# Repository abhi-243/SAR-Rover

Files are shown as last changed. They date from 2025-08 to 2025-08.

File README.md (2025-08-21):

# 🛠️ Search & Rescue Aid Robot

**A robust, low-cost, remote-controlled robot designed to aid first responders in post-disaster environments by scouting hazardous zones, identifying survivors, and streaming live footage—all while remaining compact and modular.**

---

## 📦 Contents  

- `CAD/` – Final 3D CAD models (Fusion 360)
- `STL/` – Exported 3D printable files
- `Drawings/` – Engineering drawings for fabrication
- `Code/` – ESP32-based Arduino code (motor control, IR LED, dual-camera switching, Bluetooth control via Dabble)
- `Media/` – Rendered images and beauty shots of the final design

---

## 🎯 Project Overview

Disasters like earthquakes and building collapses often trap survivors in unreachable spaces. This robot was designed to:

- **Navigate rubble** using dual-track movement and a low-profile body
- **Stream live video** via FPV cameras (day + IR night vision)
- **Be remotely controlled** using Bluetooth and the Dabble Gamepad interface
- **Be fabricated affordably** using common tools, 3D printed parts, and repurposed components (e.g. Ryobi tool batteries)

> 💡 Designed with scalability and accessibility in mind for use in developing regions or student labs.

---

## 🧠 Core Features

| Feature | Description |
|---|---|
| **Mobility** | Tank-style treads with adjustable belt tension system |
| **Dual Camera System** | Day + IR night vision with software-based switching |
| **Controller** | ESP32 microcontroller + Bluetooth + Dabble mobile interface |
| **Frame** | Acrylic chassis with 3D-printed and laser-cut elements |
| **Power** | Standard 18V Ryobi power tool battery integration |
| **Lighting** | Array of infrared and visible LEDs for enhanced visibility |

---

## 🧬 Technical Specifications

- **Microcontroller**: ESP32
- **Motor Driver**: BTS7960
- **Motors**: 12V DC gear motors (approx. 10,200 RPM)
- **Camera**: Foxeer FPV with IR switching circuit
- **Battery**: Ryobi 18V tool battery
- **Control Interface**: Dabble Gamepad via Bluetooth
- **Track System**: Dual chain + GT2 belt drive
- **Body Material**: 4.5mm Acrylic (lasercut and bent)
- **All other parts**: PETG (ABS is better, but PLA also works) 3D printed components

---

## 🧪 Code Overview

Main controller logic includes:
- Speed ramping on joystick input
- Differential drive for turns
- Camera switching via button
- IR lighting and LED toggle

```cpp
if (GamePad.isUpPressed()) {
  motors.forwardA(); motors.forwardB();
  speedness += speedAmount;
}
...
if (GamePad.isTrianglePressed()) {
  digitalWrite(cam, HIGH);  // Toggle camera
}
```

> 📂 See [`/Code/main.ino`](./Code/main.ino) for full source.

---

## 🖨️ Manufacturing Instructions

- Print STL files using PLA+ with 100% infill for structural components.
- Laser cut acrylic sheets using templates provided in `/Drawings/`.
- Bend chassis with acrylic bender based on Fusion 360 flat patterns.
- Assemble with M3–M5 bolts and collars per engineering drawings.

---

## 🧪 Testing Notes

- All individual systems (motors, cameras, Bluetooth) confirmed functional
- Movement subsystem had traction issues due to belt tensioning—future revisions planned

---

## 📸 Gallery

### Final Design

| Render1 | Render2 |
|:---:|:---:|
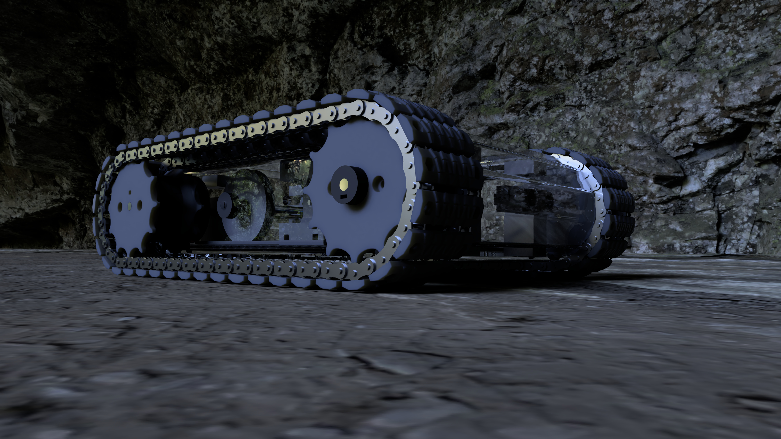
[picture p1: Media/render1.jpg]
Render3
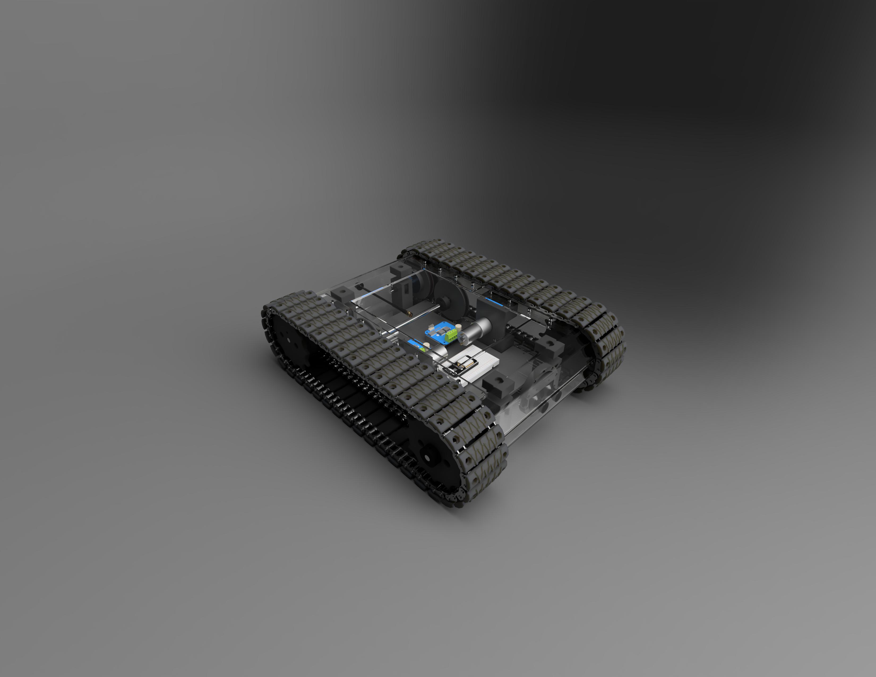
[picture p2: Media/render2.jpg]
Render4
|  |  |

----

### Animation

[Watch the demo](https://youtu.be/A4exE1CUXJw)

---

## 📚 Inspiration

Inspired by:
- [rctestflight snowcat robot](https://www.youtube.com/@rctestflight)
- Search-and-rescue robotics in earthquake zones
- Open-source robotics communities and Thingiverse designs

---

## 🤝 Acknowledgements

- **Mentors**: Mr. Jin Son (Design Theory), Mr. Rowan Simpson (Engineering)
- **Special thanks** to online creators and FPV drone community for documentation and hardware guidance

---

## 🧾 License

This project is released as **open hardware** and **open-source software**. Reuse, remix, and improve freely with attribution.

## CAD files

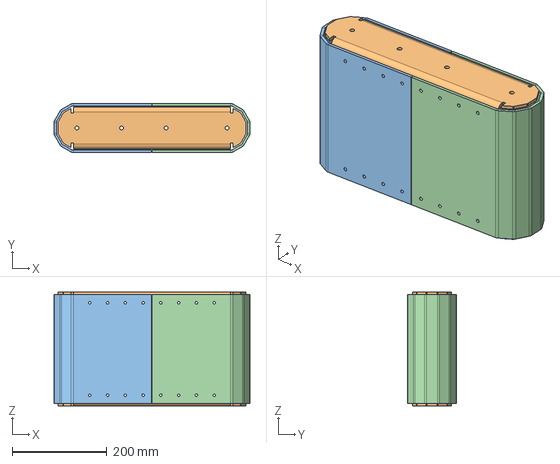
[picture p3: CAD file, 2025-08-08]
CAD/Body.step
413.5 x 103.8 x 240.0 mm

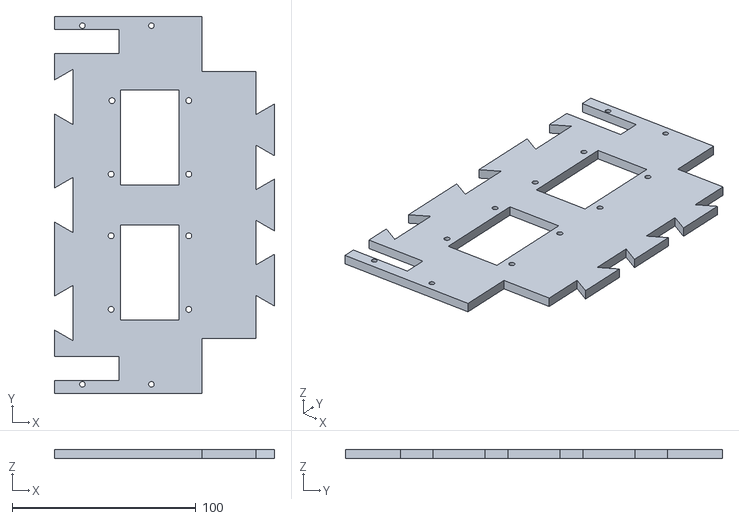
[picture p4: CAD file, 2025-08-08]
STLs/electronics mount-c.stl
119.7 x 205.0 x 5.00

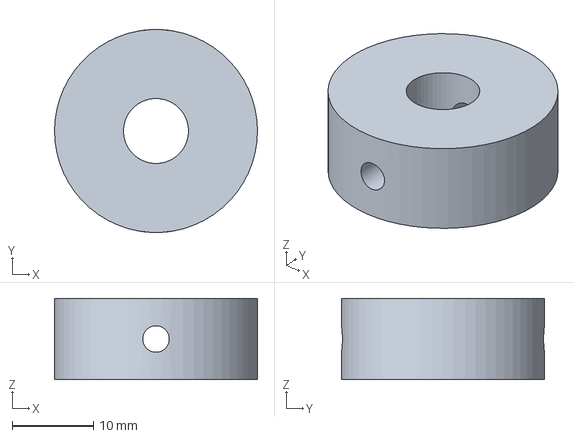
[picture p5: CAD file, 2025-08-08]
CAD/Shaft Collars.step
25.0 x 25.0 x 10.0 mm

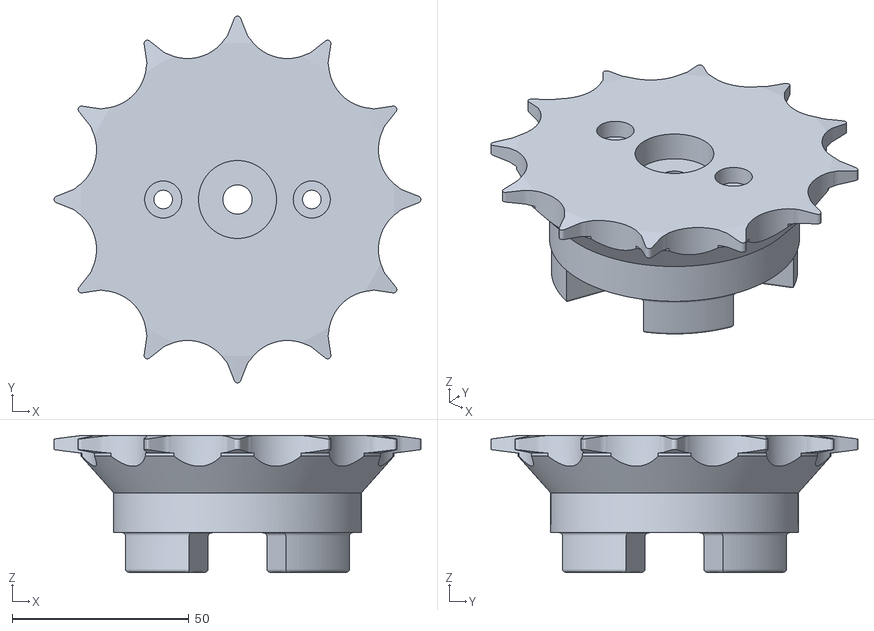
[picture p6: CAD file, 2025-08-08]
STLs/Sprocket v9 A.stl
103.8 x 103.8 x 38.8

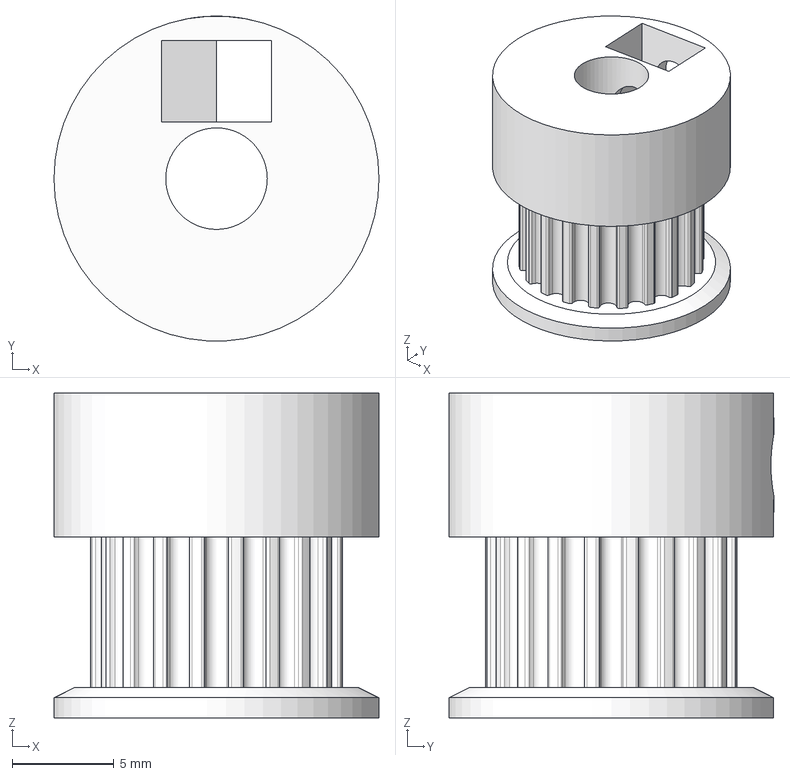
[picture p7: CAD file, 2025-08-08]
CAD/GT2 20T.step
16.0 x 16.0 x 16.0 mm

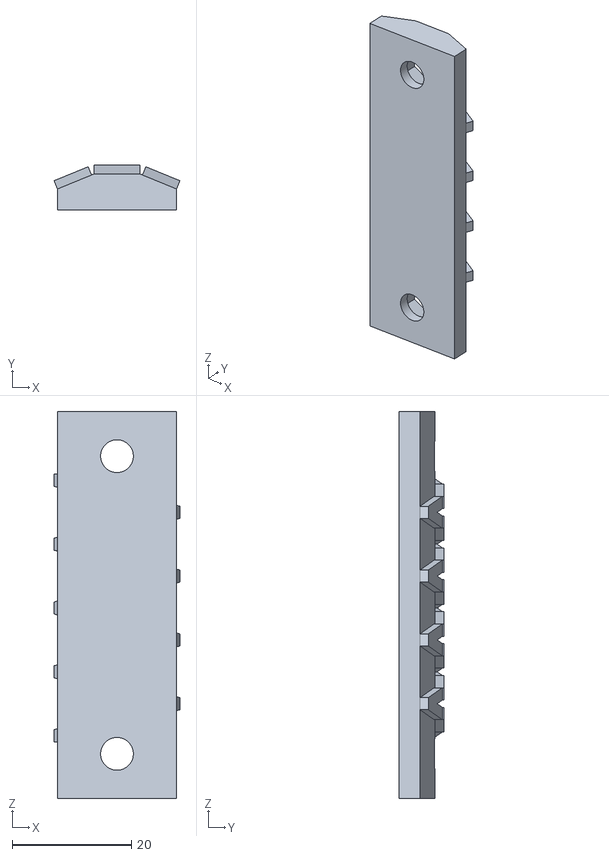
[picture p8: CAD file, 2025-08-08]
STLs/Tread Design 5.stl
21.1 x 7.50 x 65.0

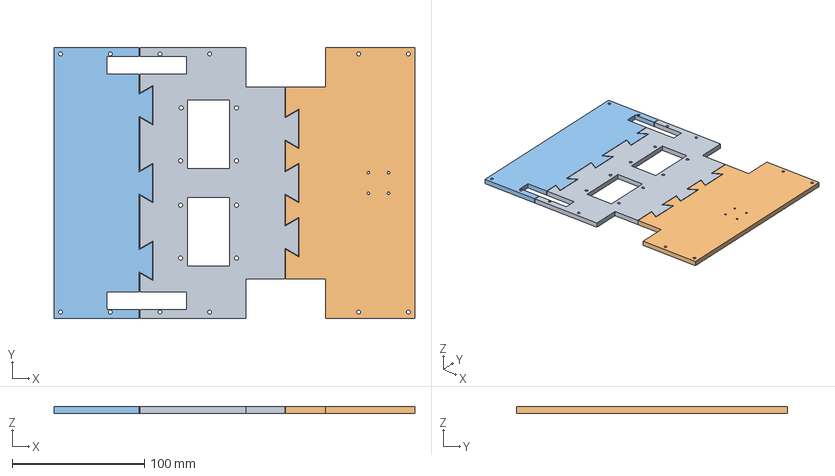
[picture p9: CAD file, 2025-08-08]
CAD/Electronics Mount.step
272.6 x 205.0 x 5.00 mm

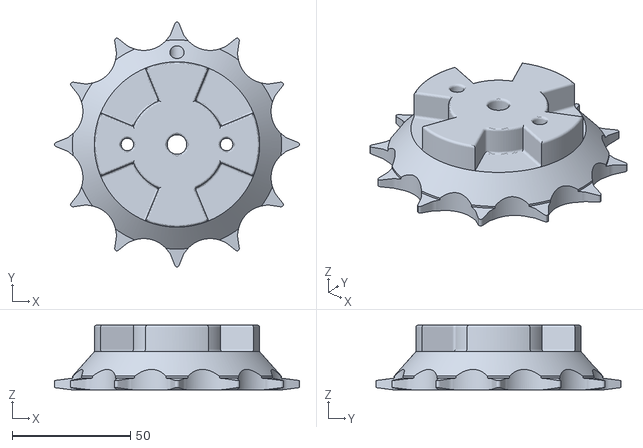
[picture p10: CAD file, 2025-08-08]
STLs/Drive Sprocket v9 B.stl
103.8 x 103.8 x 27.5

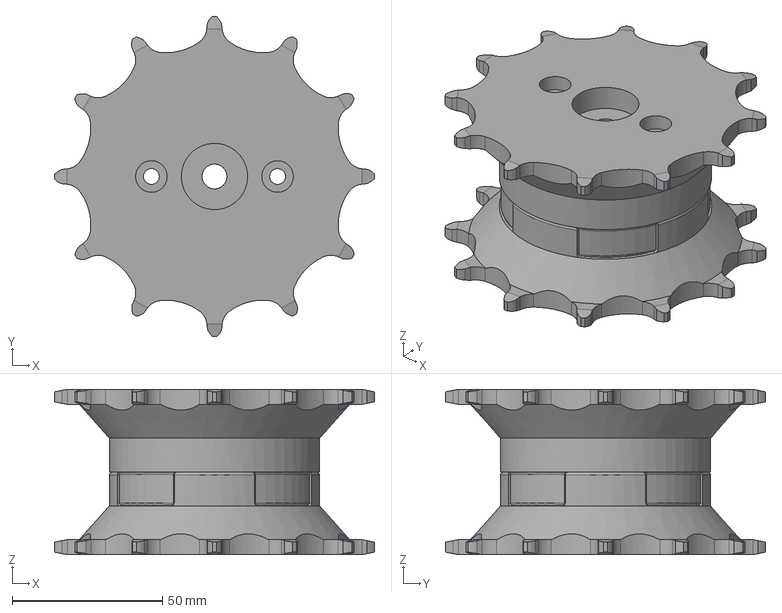
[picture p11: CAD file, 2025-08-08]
CAD/Sprocket.step
106.5 x 106.5 x 55.0 mm

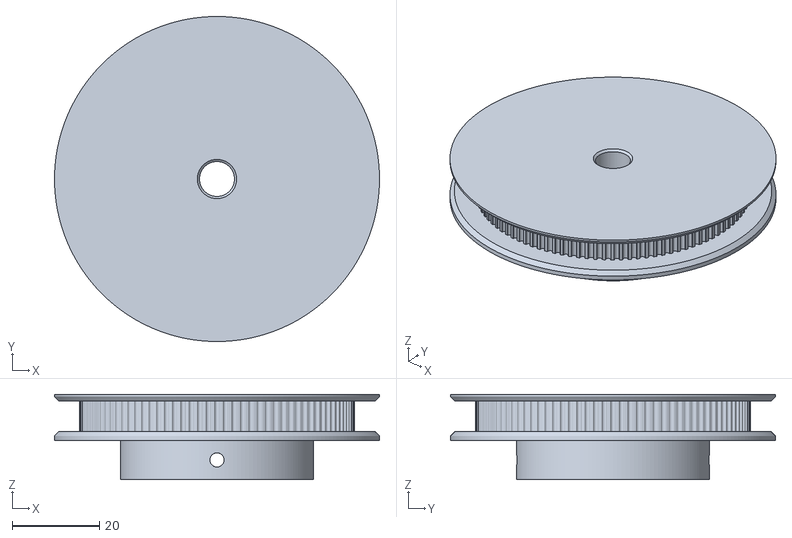
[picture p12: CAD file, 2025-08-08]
STLs/GT2 100T 8mm.stl
74.5 x 74.5 x 19.5

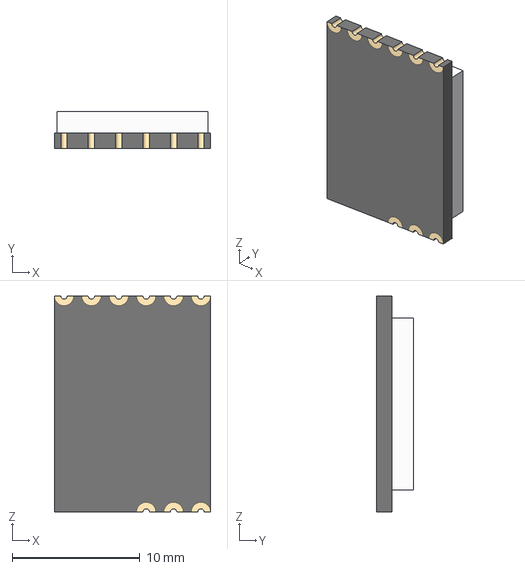
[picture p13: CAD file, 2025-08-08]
CAD/Rush Tank Tiny 5.8GHz VTX w Smart Audio.step
12.2 x 2.90 x 16.9 mm

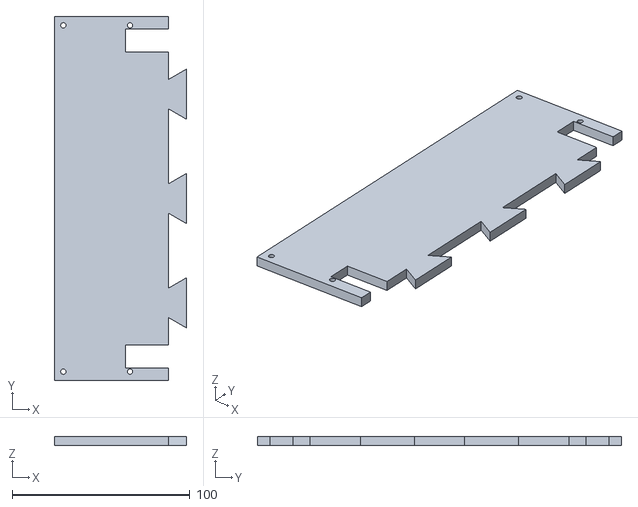
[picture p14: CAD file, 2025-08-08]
STLs/electronics mount-b.stl
74.3 x 205.0 x 5.00

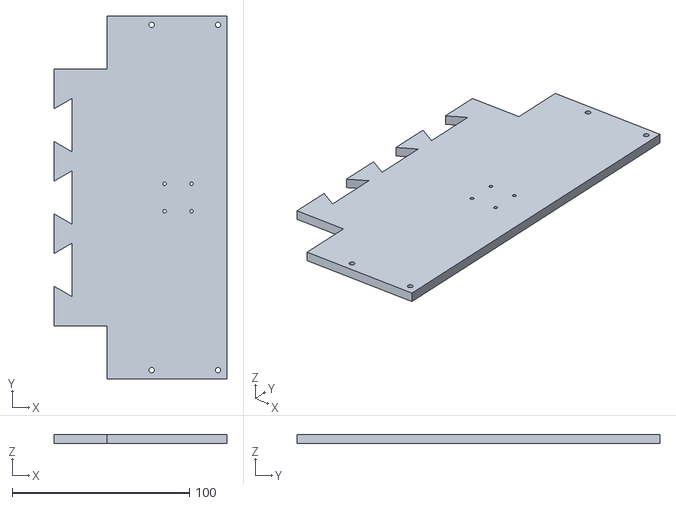
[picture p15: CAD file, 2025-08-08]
STLs/electronics mount-a.stl
97.6 x 205.0 x 5.00

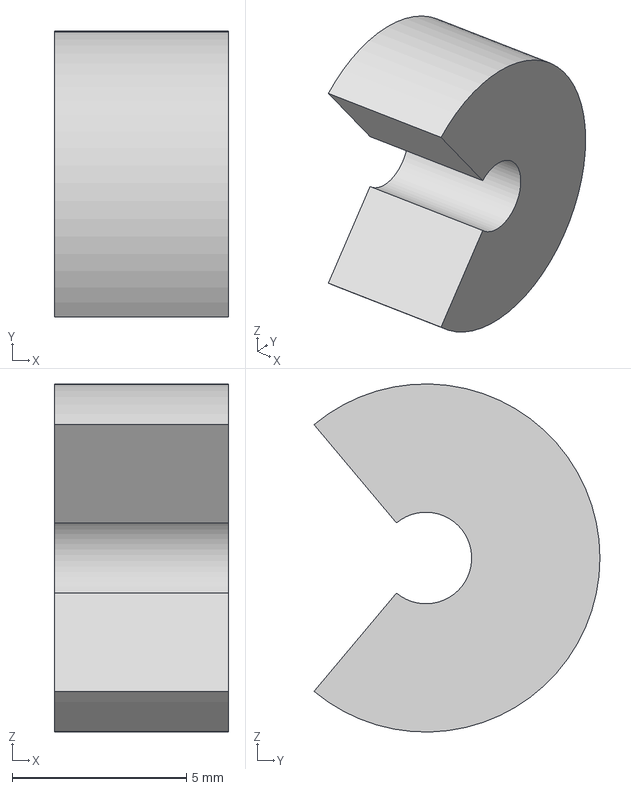
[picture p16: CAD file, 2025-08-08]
CAD/collar.step
5.00 x 8.21 x 10.00 mm

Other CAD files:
CAD/Drive Sprocket.step
STLs/light mount.stl
CAD/Shaft.step
STLs/Drive Sprocket v9 A.stl
CAD/36RPM 12VDC Reversible Gearhead Motor.step
CAD/BTS7960 H-Bridge Module.step
CAD/Camera.step
CAD/Combined 2.step
CAD/Lid Handles.step
CAD/Lumenier Double AXII 2 Long Range Antenna 5.8GHz Straight SMA RHCP.step
CAD/NodeMCU-32S-USBC-38pin-Narrow.step
CAD/Parametric GT2 100 pulley.step
CAD/Rush Tank Tiny Sled.step
CAD/Shaft Support.step
CAD/Treads.step
CAD/ViFly Cam Switcher.step
CAD/collar.dxf
CAD/motor mount.step
STLs/Chain_lock.stl
STLs/GT2 20T 5mm.stl
STLs/Shaft Collar 1.stl
STLs/Sprocket v9 B.stl
STLs/motor mount.stl
STLs/support 1.stl
STLs/support 2.stl
STLs/washer.stl

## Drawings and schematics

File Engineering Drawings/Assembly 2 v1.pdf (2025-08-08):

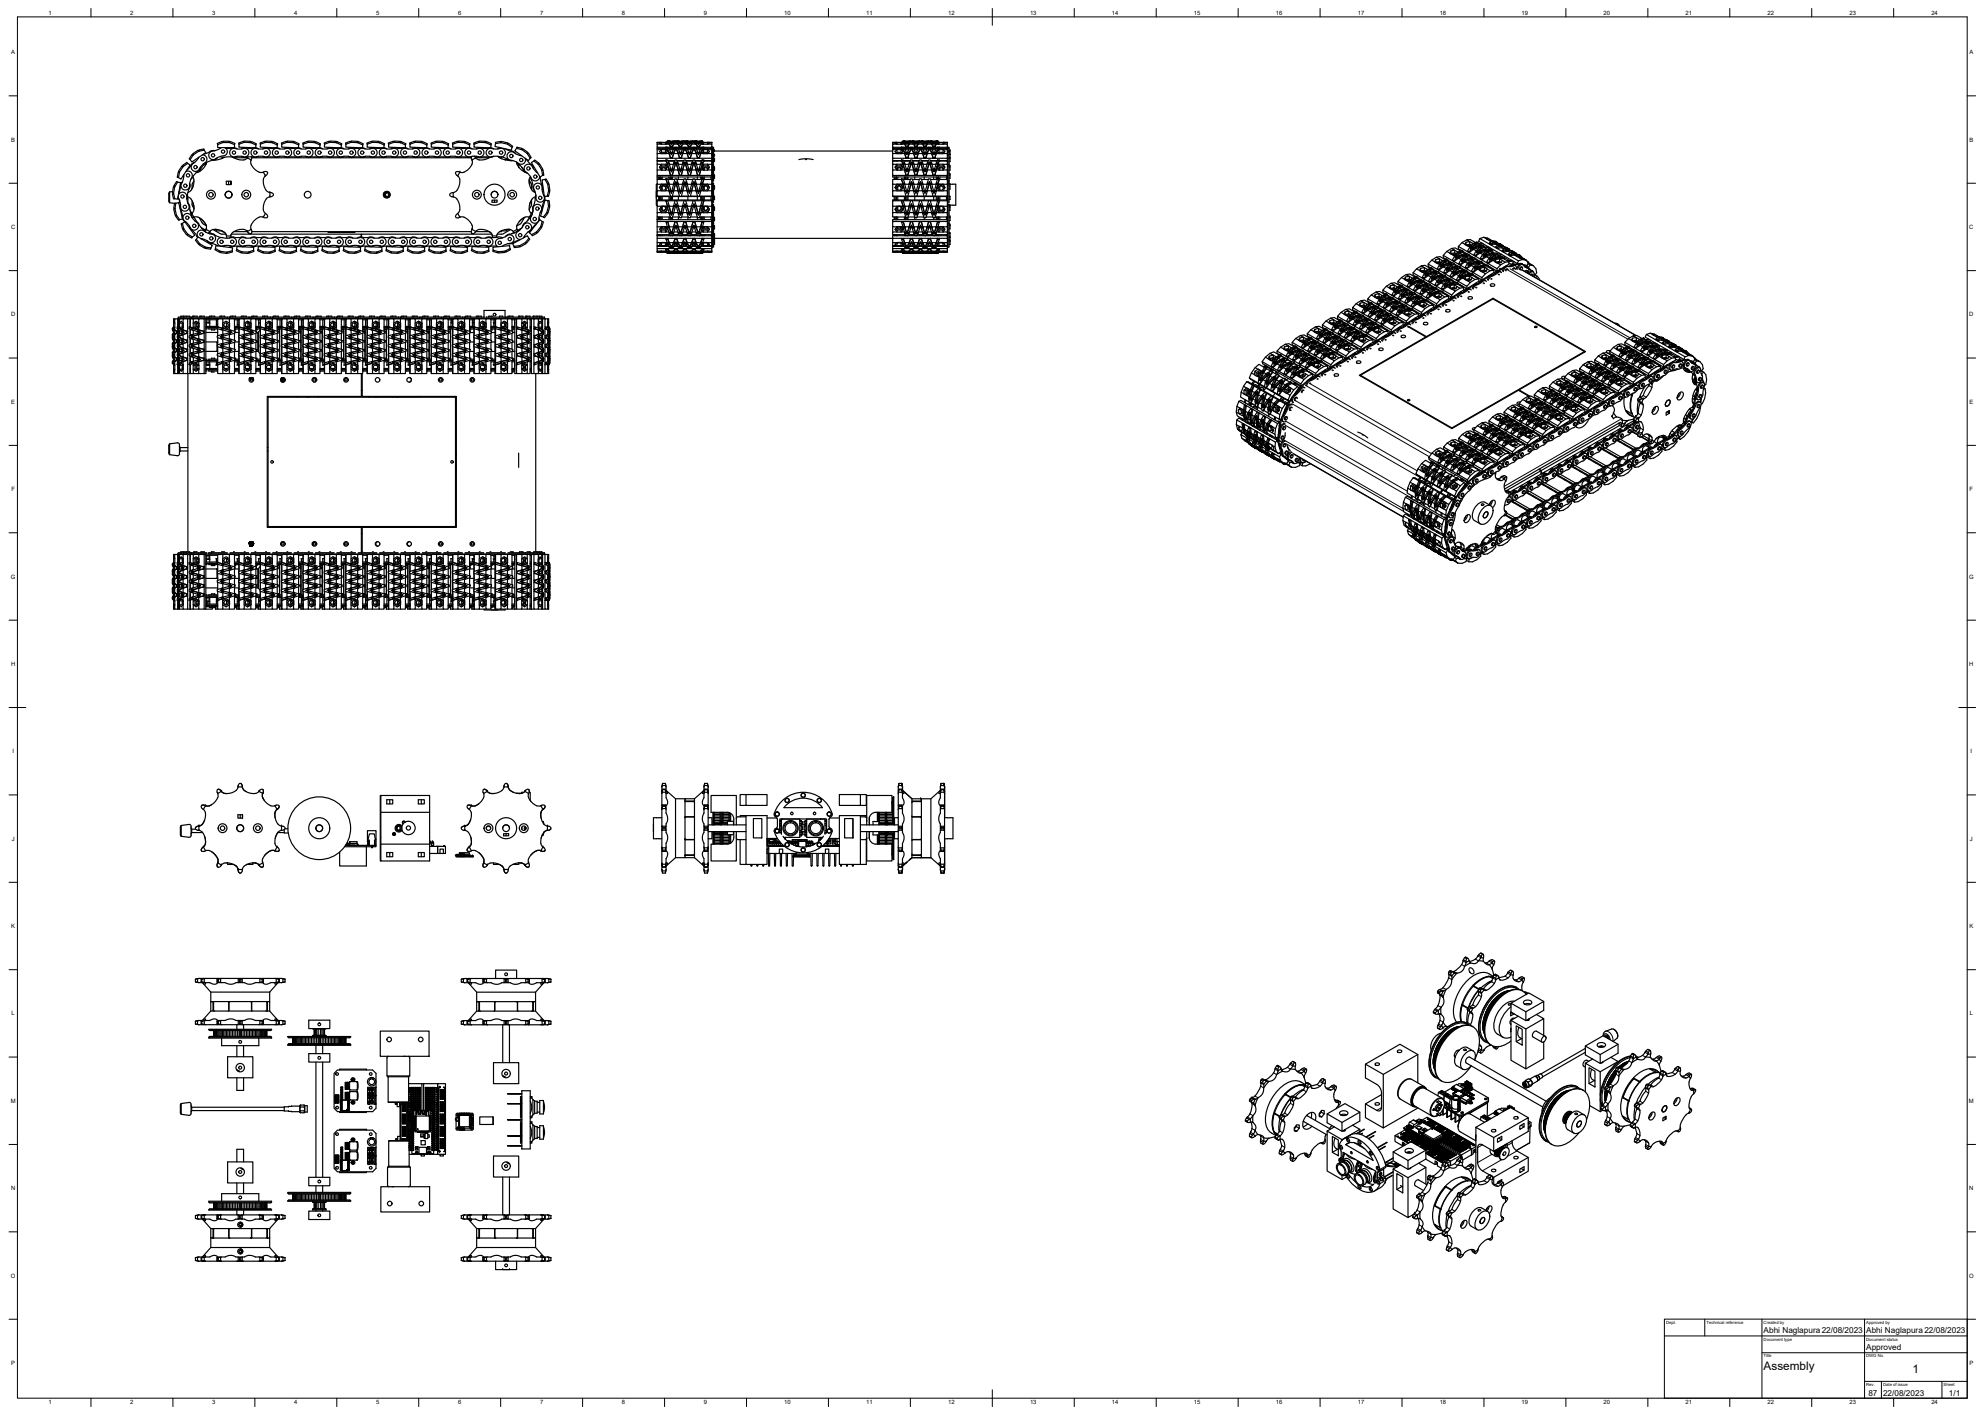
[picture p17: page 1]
24 BADCFEHGIKJMLONP; BADCFEHGIKJMLONP Dept.; Technical reference; Created by; Approved by Document type; Document status Title; DWG No. Rev.; Date of issue; Sheet 87 22/08/2023 Approved 22/08/2023; 22/08/2023 1/1 Assembly; 1 Abhi Naglapura; Abhi Naglapura

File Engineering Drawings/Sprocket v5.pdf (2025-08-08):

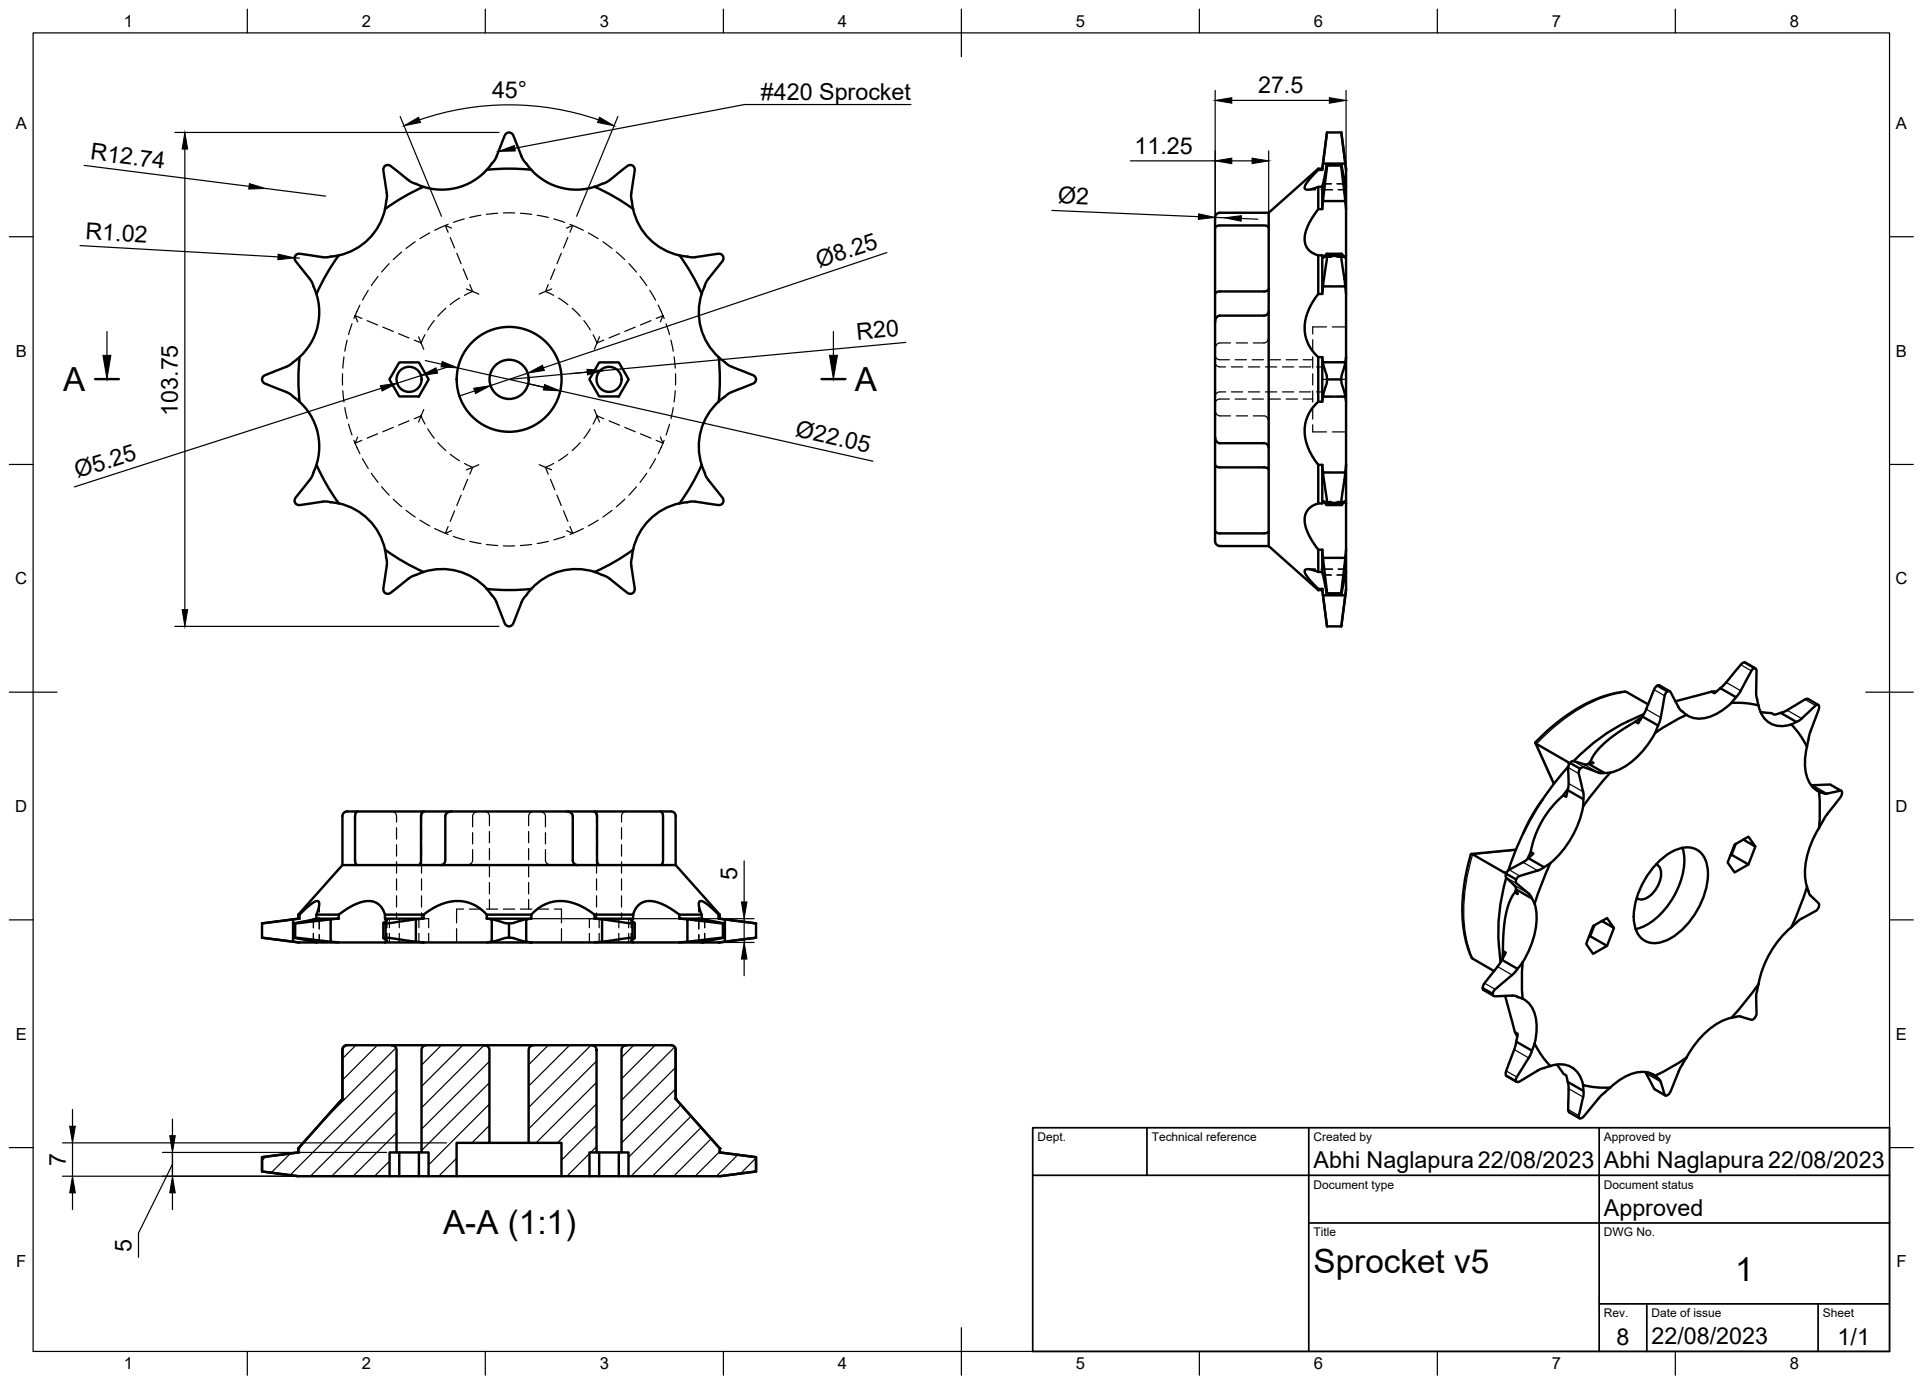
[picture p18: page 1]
Title; DWG No.; Rev.; Date of issue; Sheet; Sprocket v5; 27.5 103.75 #420 Sprocket

Dept. | Technical reference | Created by Abhi Naglapura 22/08/2023 | Approved by Abhi Naglapura 22/08/2023

Document type | Document status Approved

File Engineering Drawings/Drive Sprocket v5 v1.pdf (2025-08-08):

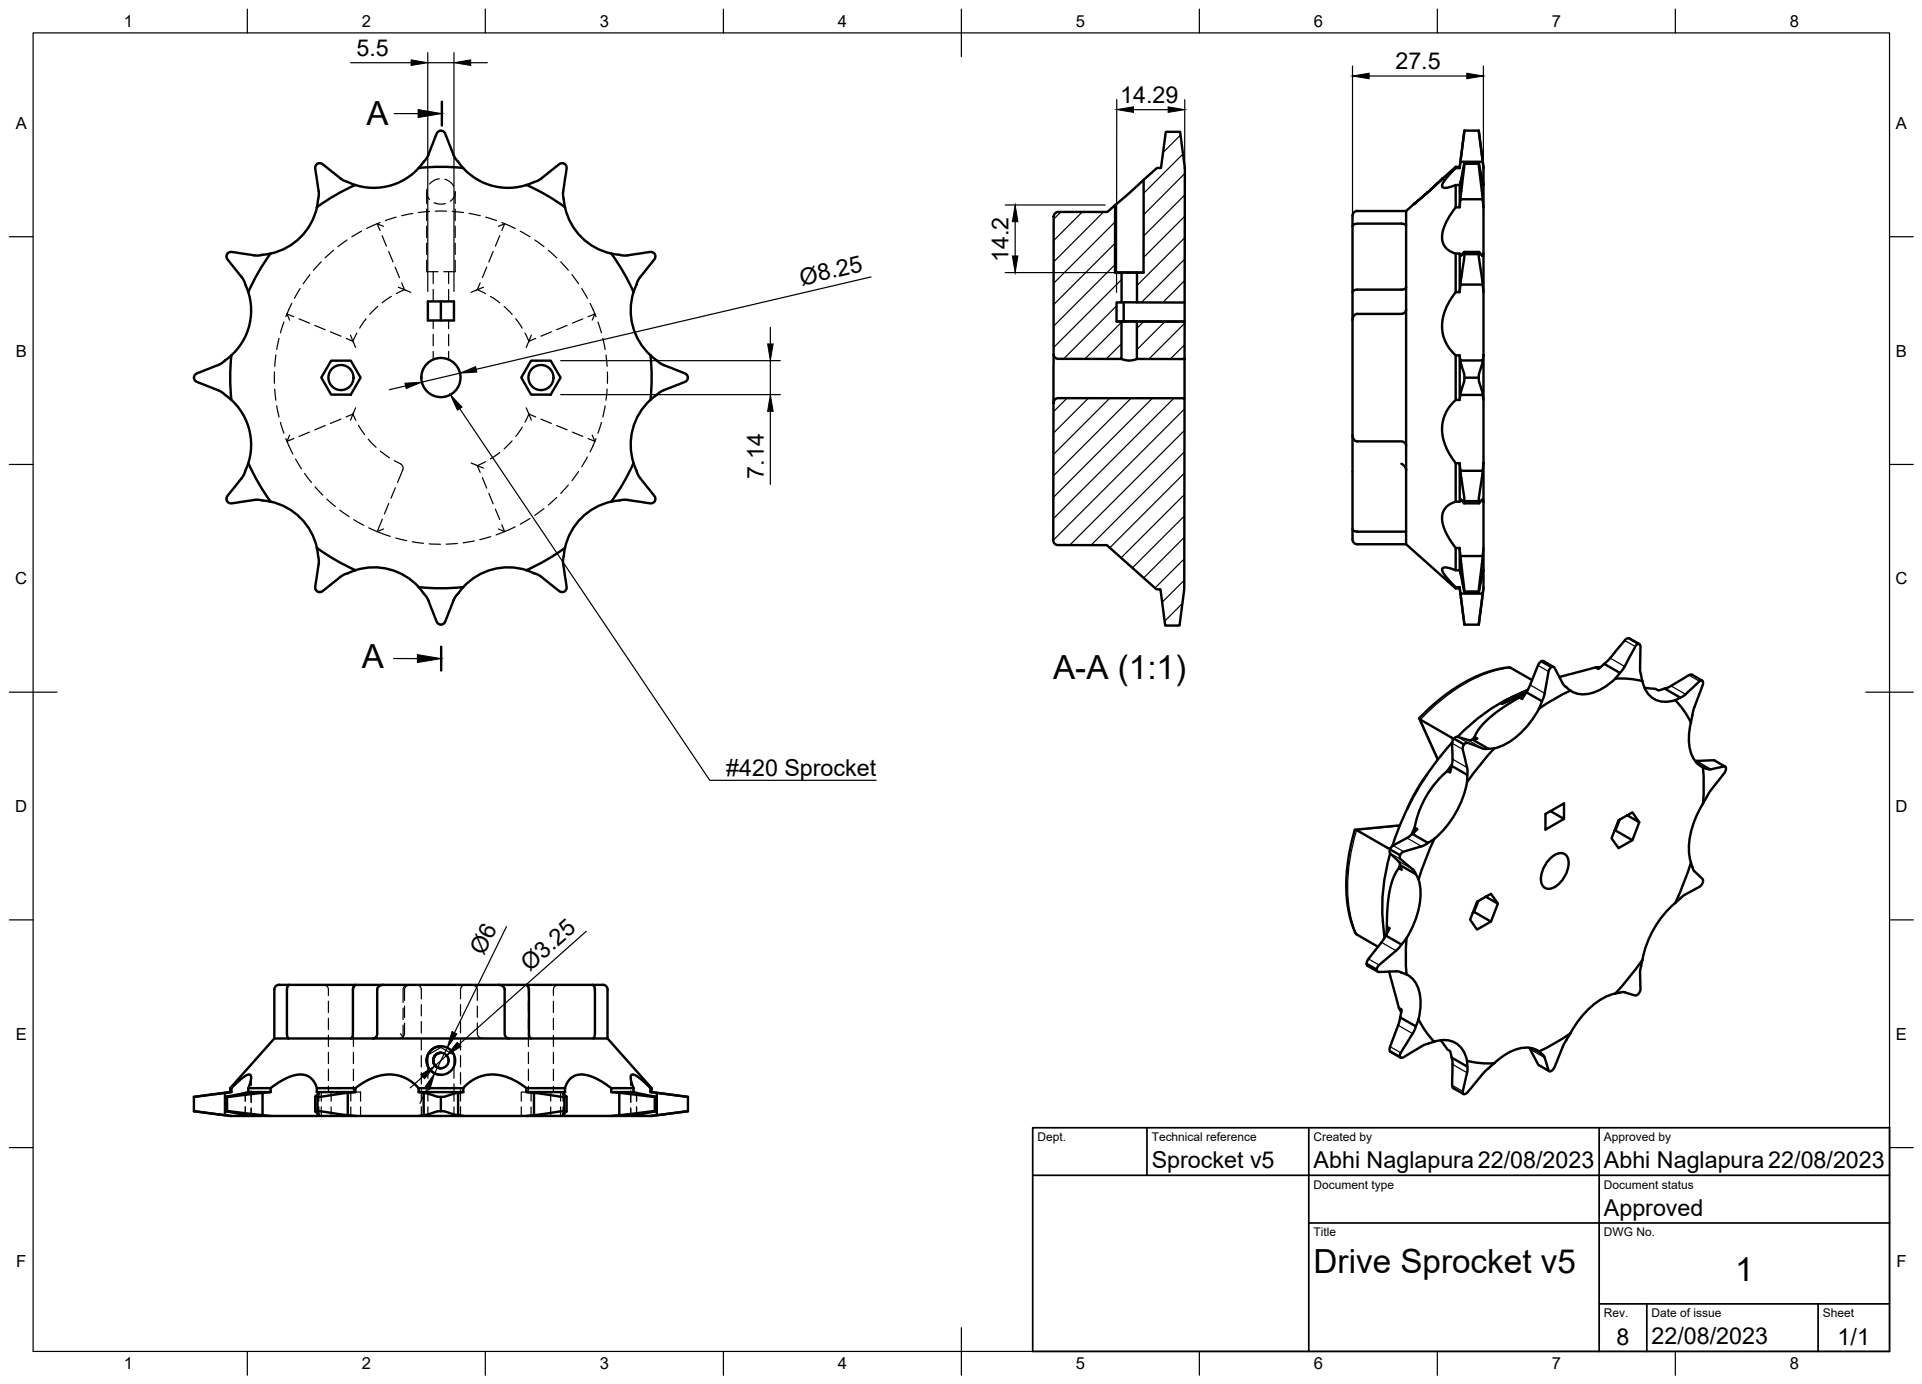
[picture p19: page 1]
Title; DWG No.; Rev.; Date of issue; Sheet; Drive Sprocket v5; Sprocket v5; Abhi Naglapura; Abhi Naglapura 7.14; #420 Sprocket

Dept. | Technical reference | Created by 22/08/2023 | Approved by 22/08/2023

Document type | Document status Approved

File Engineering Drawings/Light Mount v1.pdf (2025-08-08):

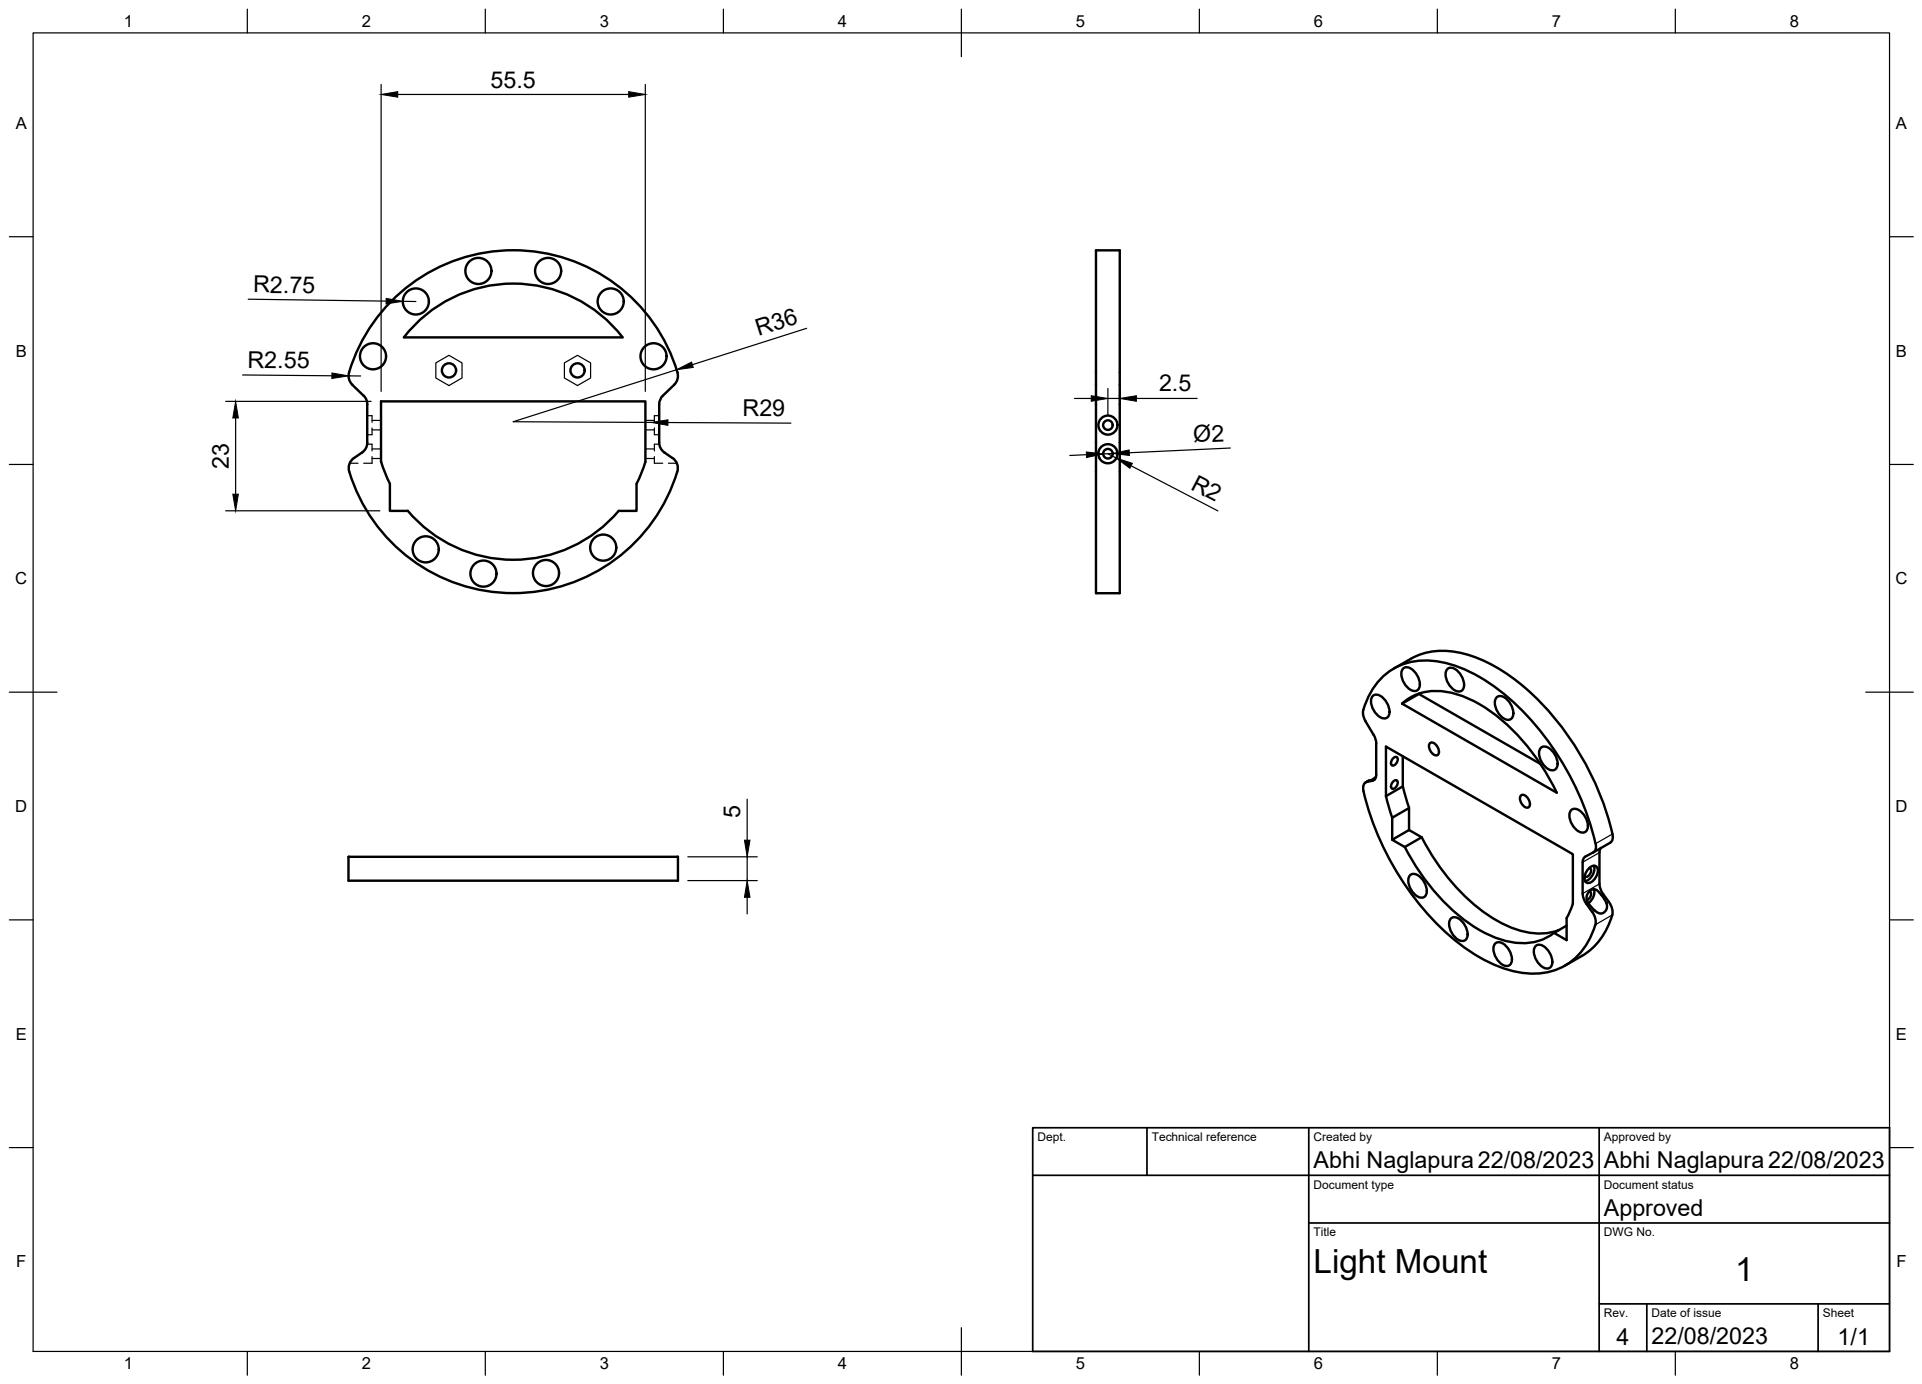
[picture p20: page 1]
Title; DWG No.; Rev.; Date of issue; Sheet; Light Mount

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

Document type | Document status Approved

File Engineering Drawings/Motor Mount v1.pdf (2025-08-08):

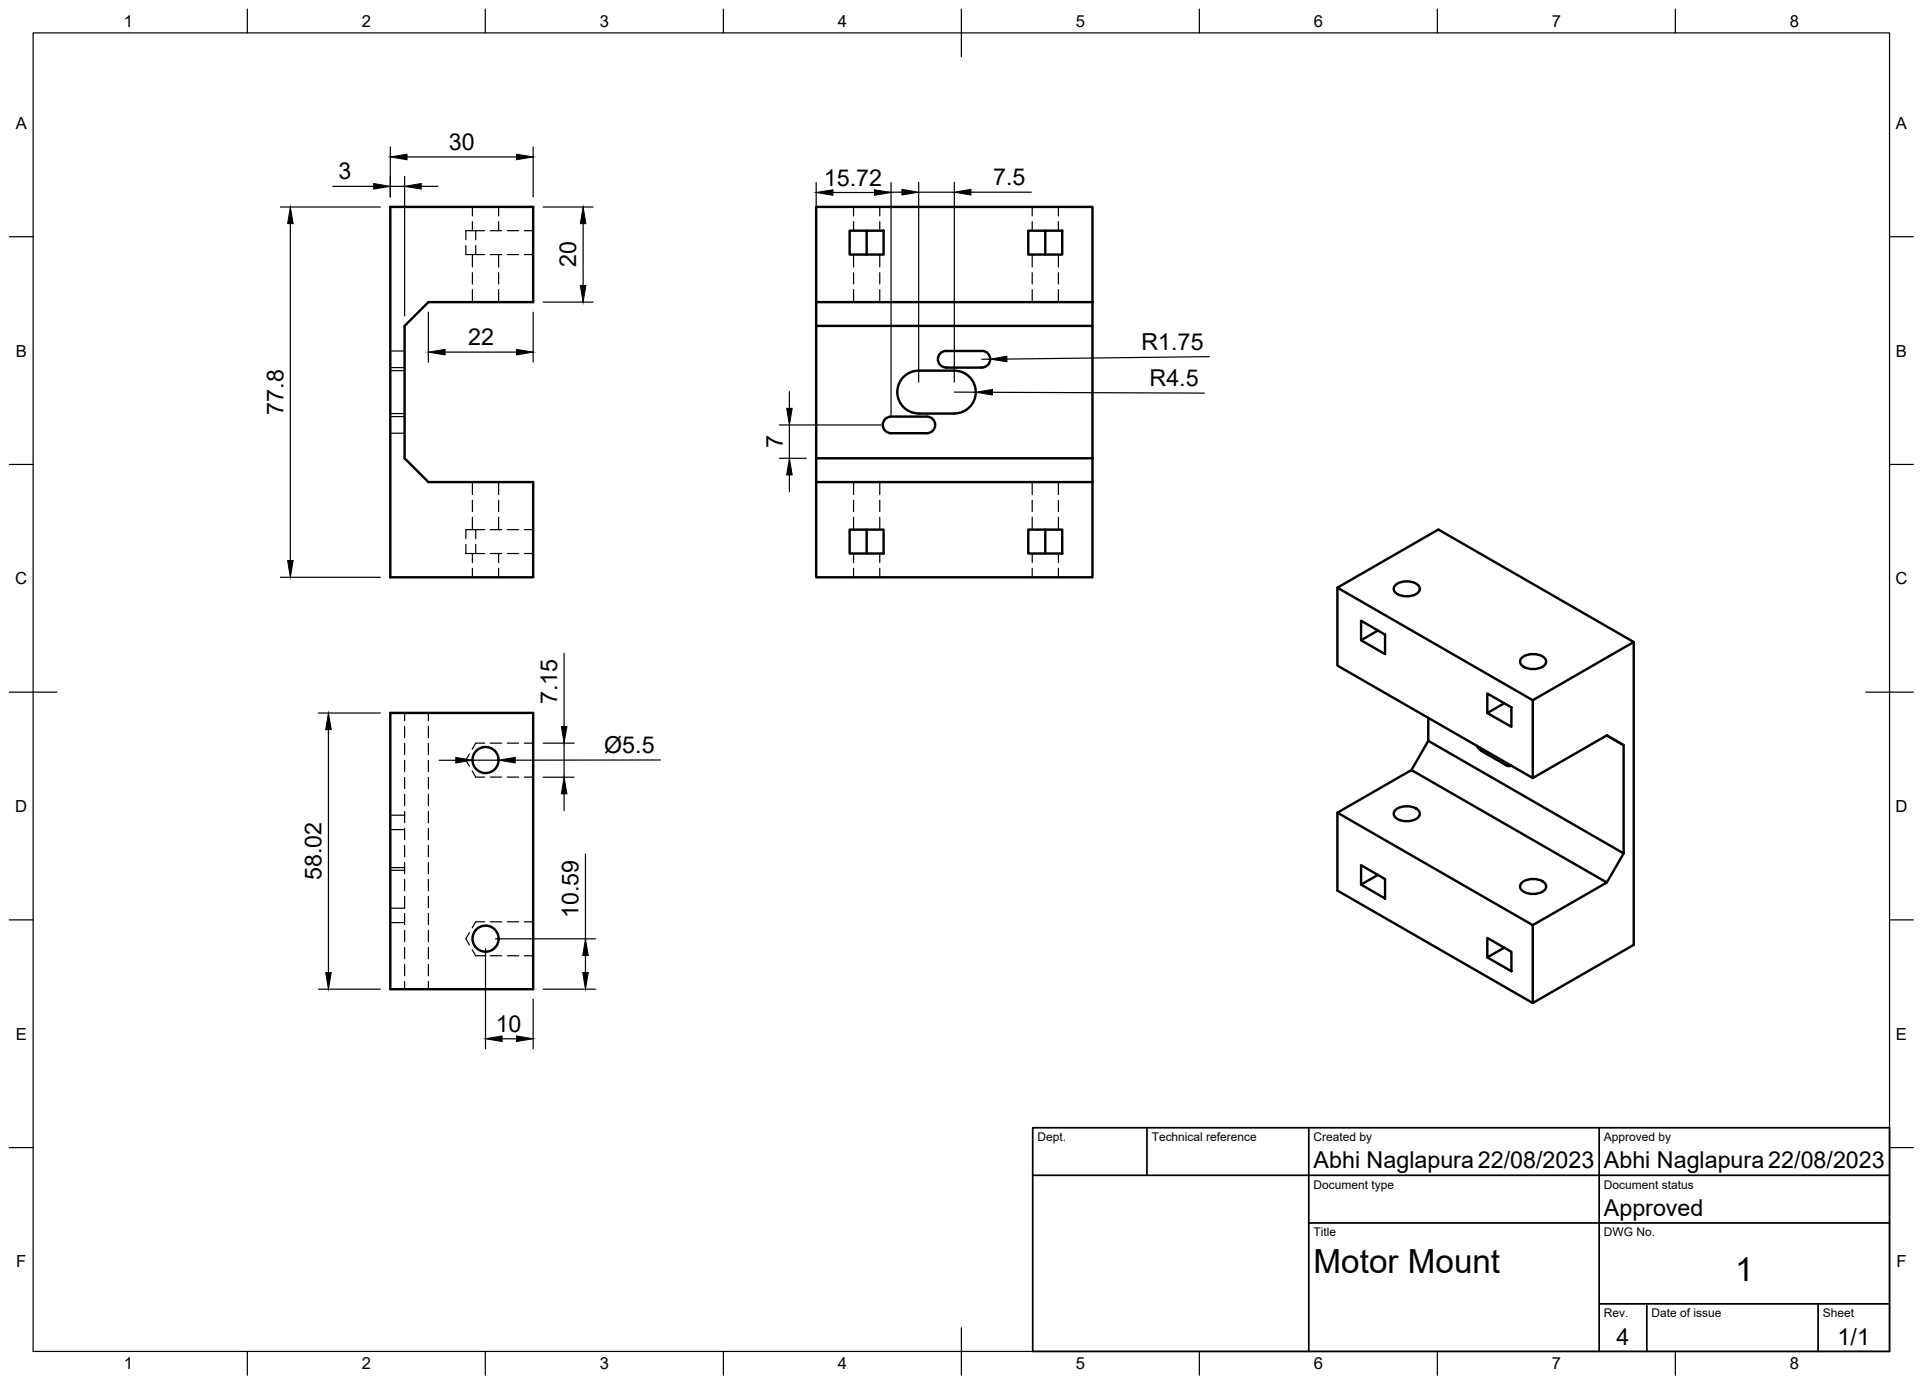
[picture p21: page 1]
Title; DWG No.; Rev.; Date of issue; Sheet; Motor Mount

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

Document type | Document status Approved

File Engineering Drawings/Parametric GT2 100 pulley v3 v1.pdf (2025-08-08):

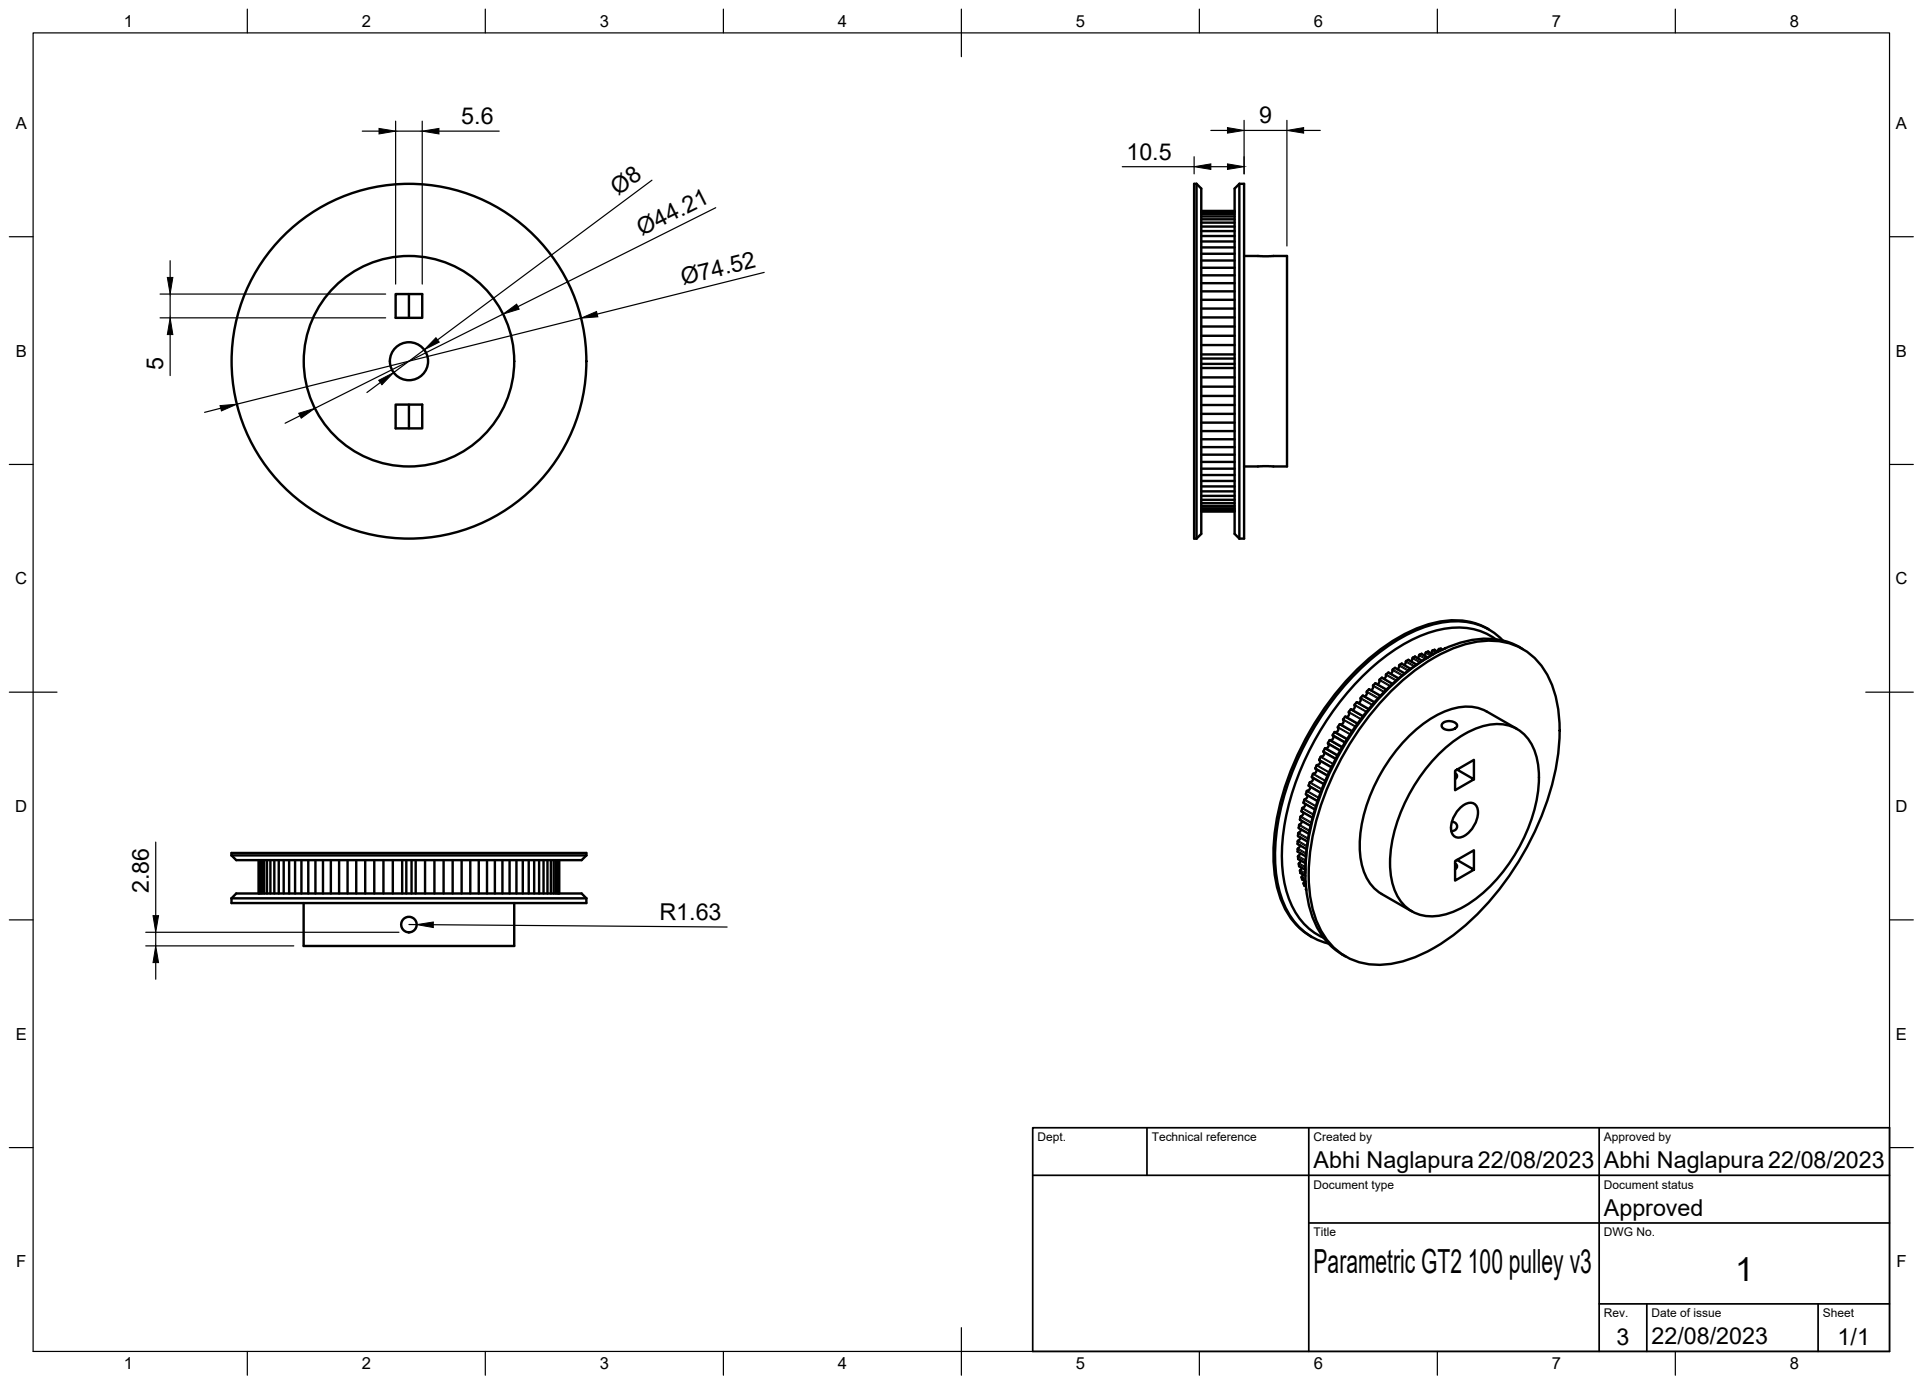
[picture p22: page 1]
Title; DWG No.; Rev.; Date of issue; Sheet; Parametric GT2 100 pulley v3

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

Document type | Document status Approved

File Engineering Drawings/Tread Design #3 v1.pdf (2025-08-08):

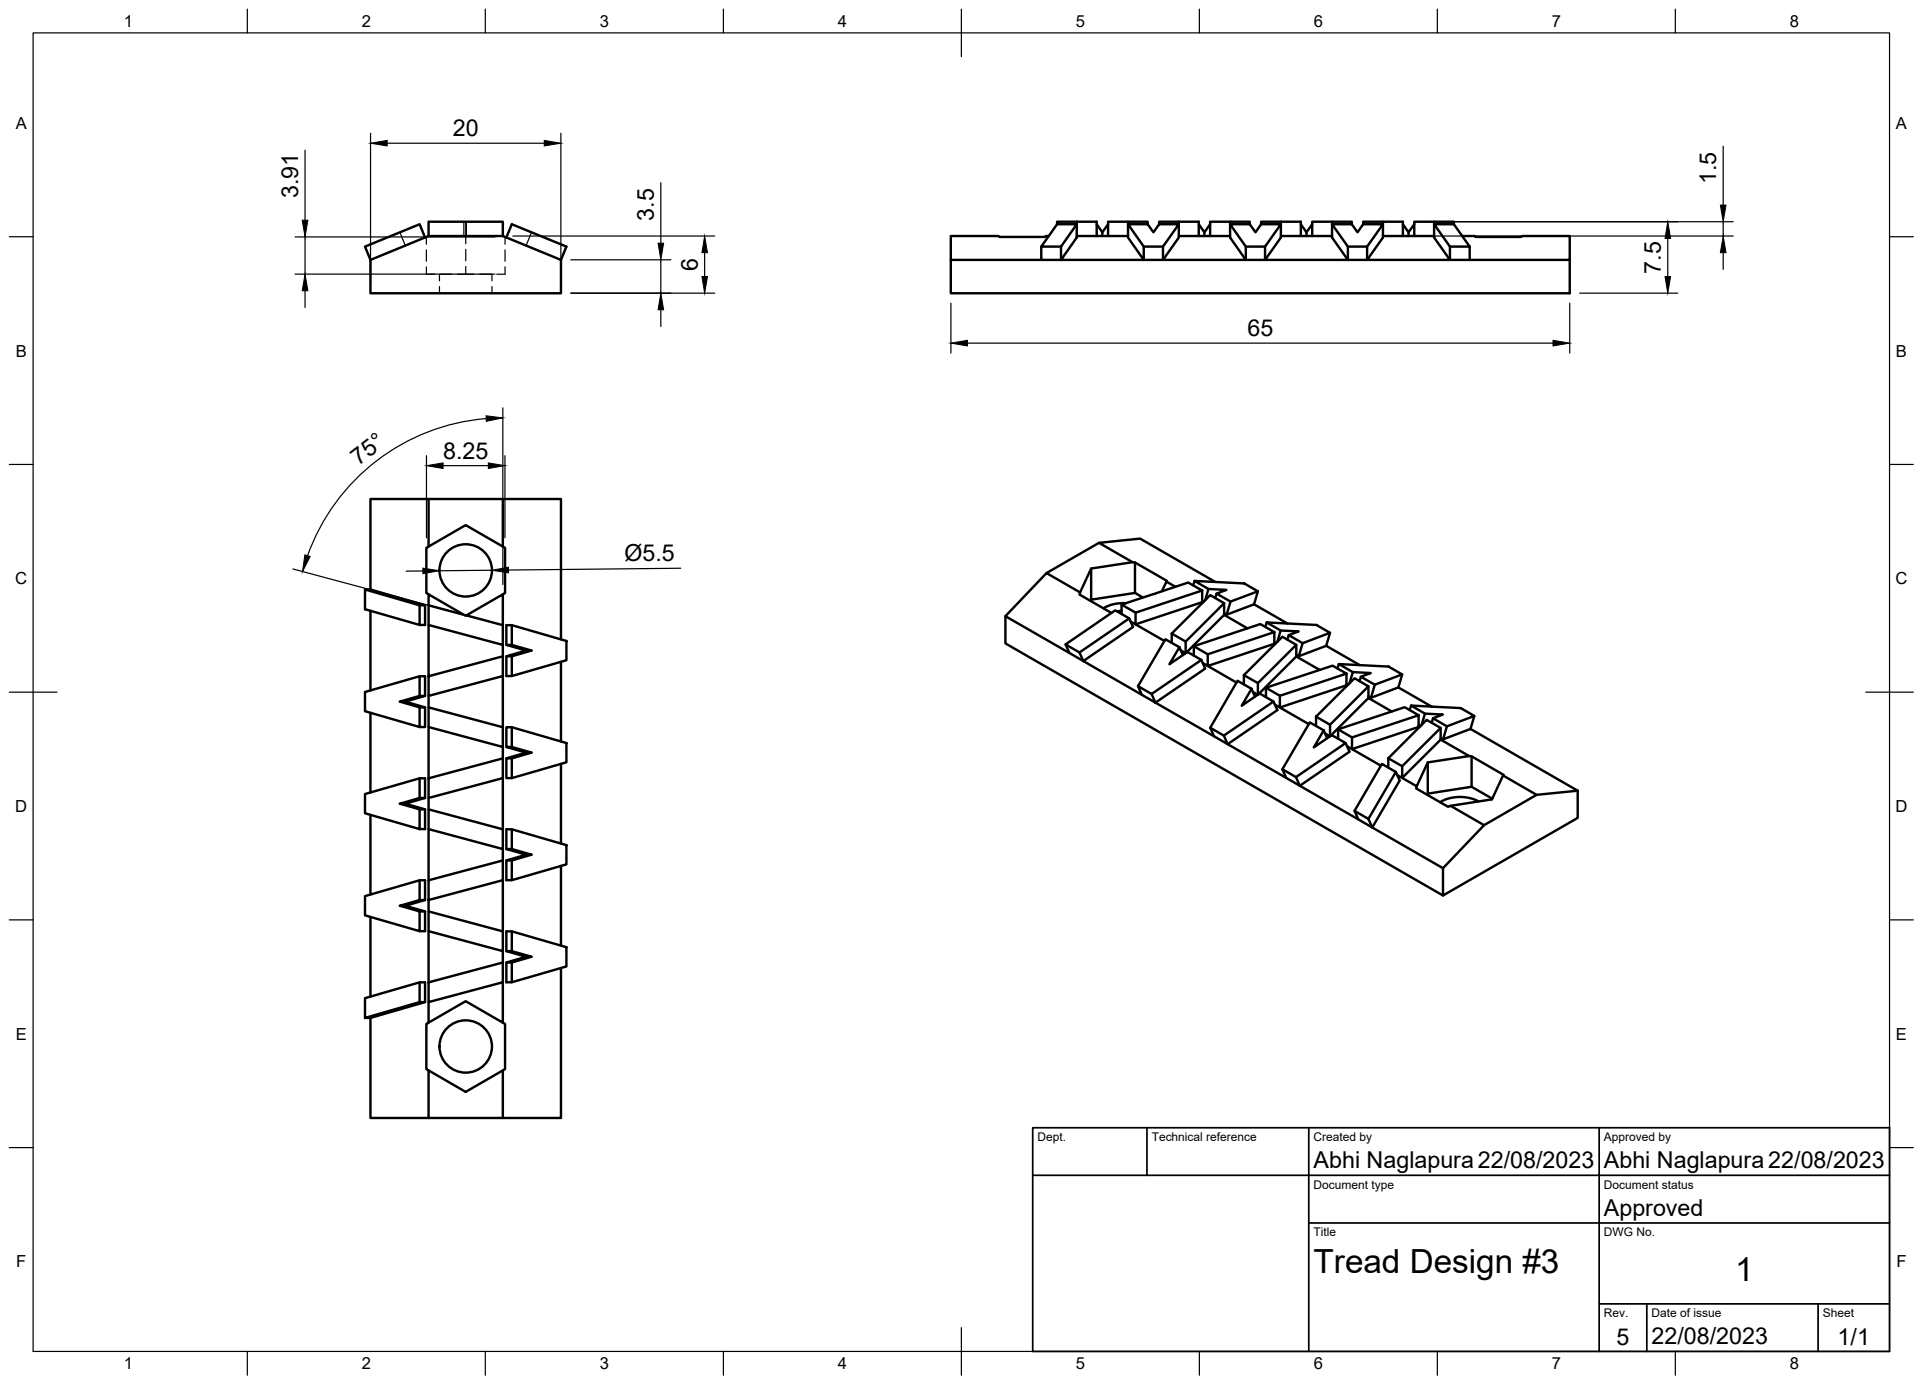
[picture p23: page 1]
Title; DWG No.; Rev.; Date of issue; Sheet; Tread Design #3

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

Document type | Document status Approved

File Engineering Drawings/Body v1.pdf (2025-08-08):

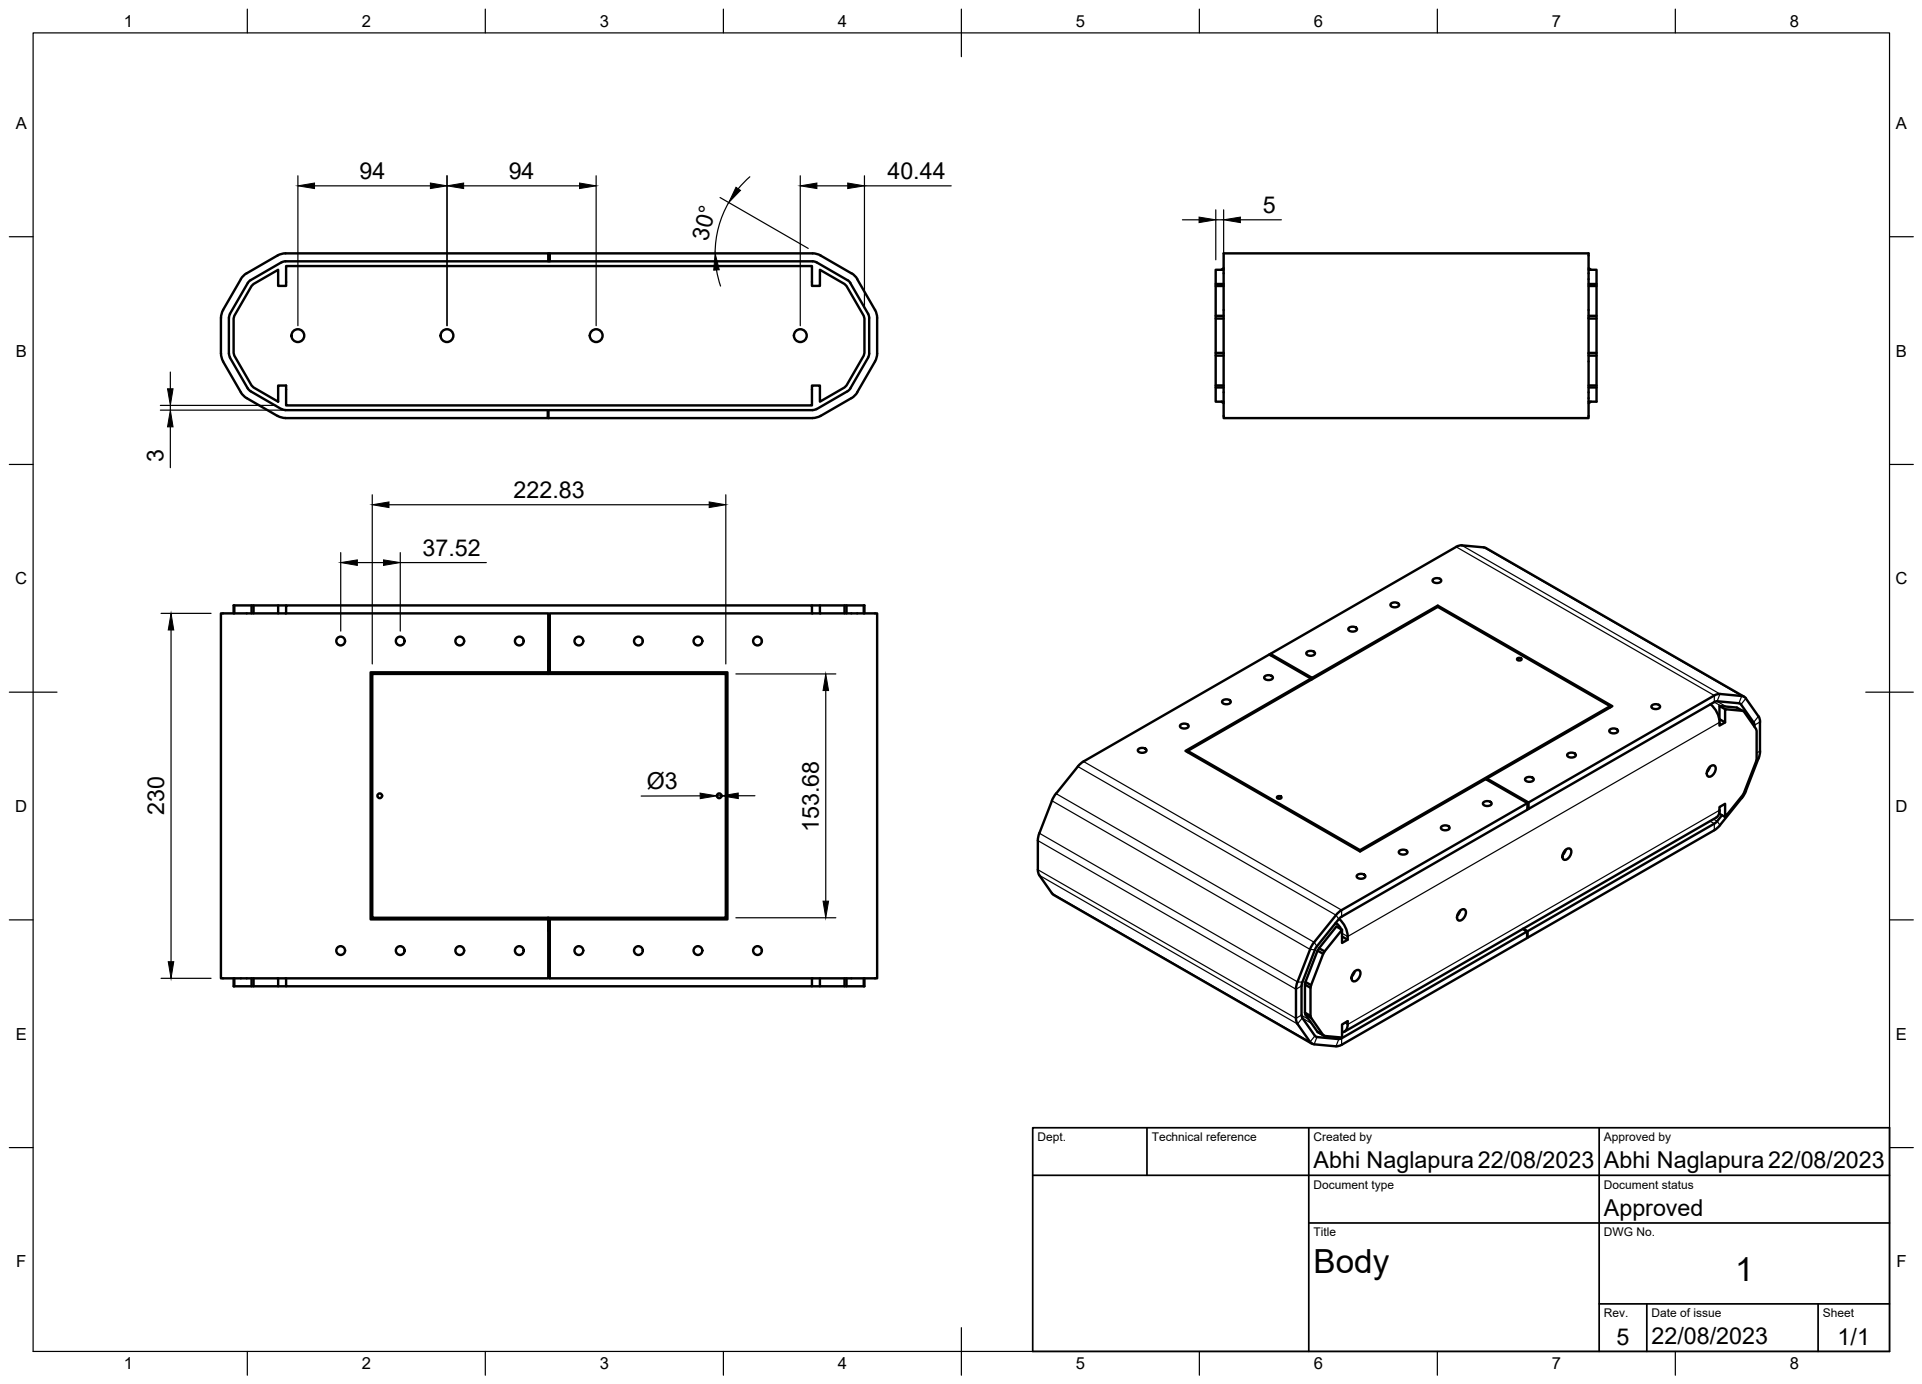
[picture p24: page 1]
Title; DWG No.; Rev.; Date of issue; Sheet

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

Document type | Document status Approved

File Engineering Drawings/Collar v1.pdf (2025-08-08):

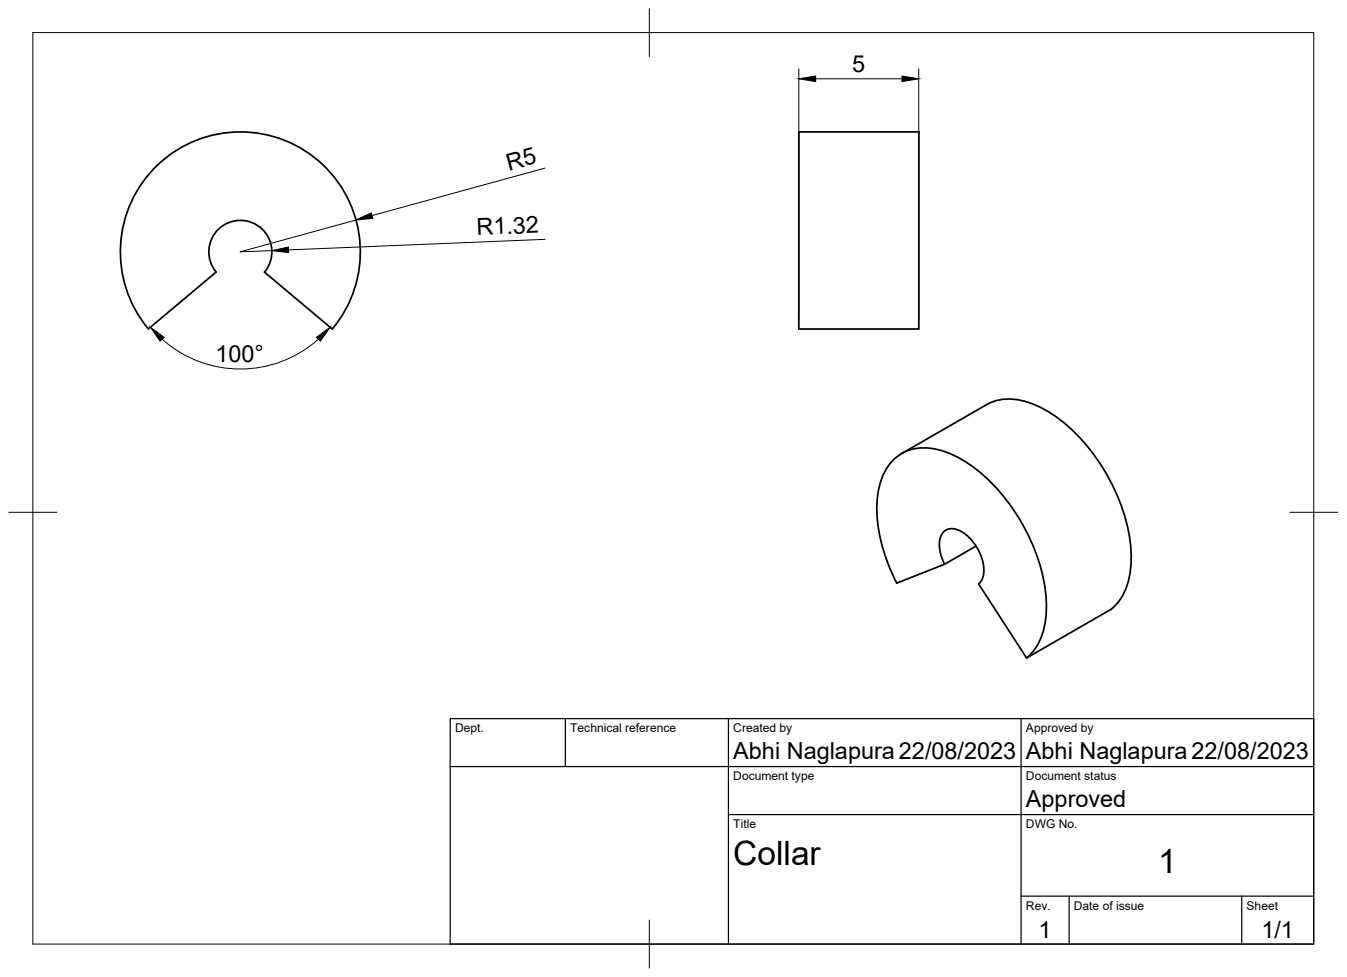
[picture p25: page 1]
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

Document type | Document status Approved

Title Collar | DWG No. 1

Rev. 1 | Date of issue | Sheet 1/1

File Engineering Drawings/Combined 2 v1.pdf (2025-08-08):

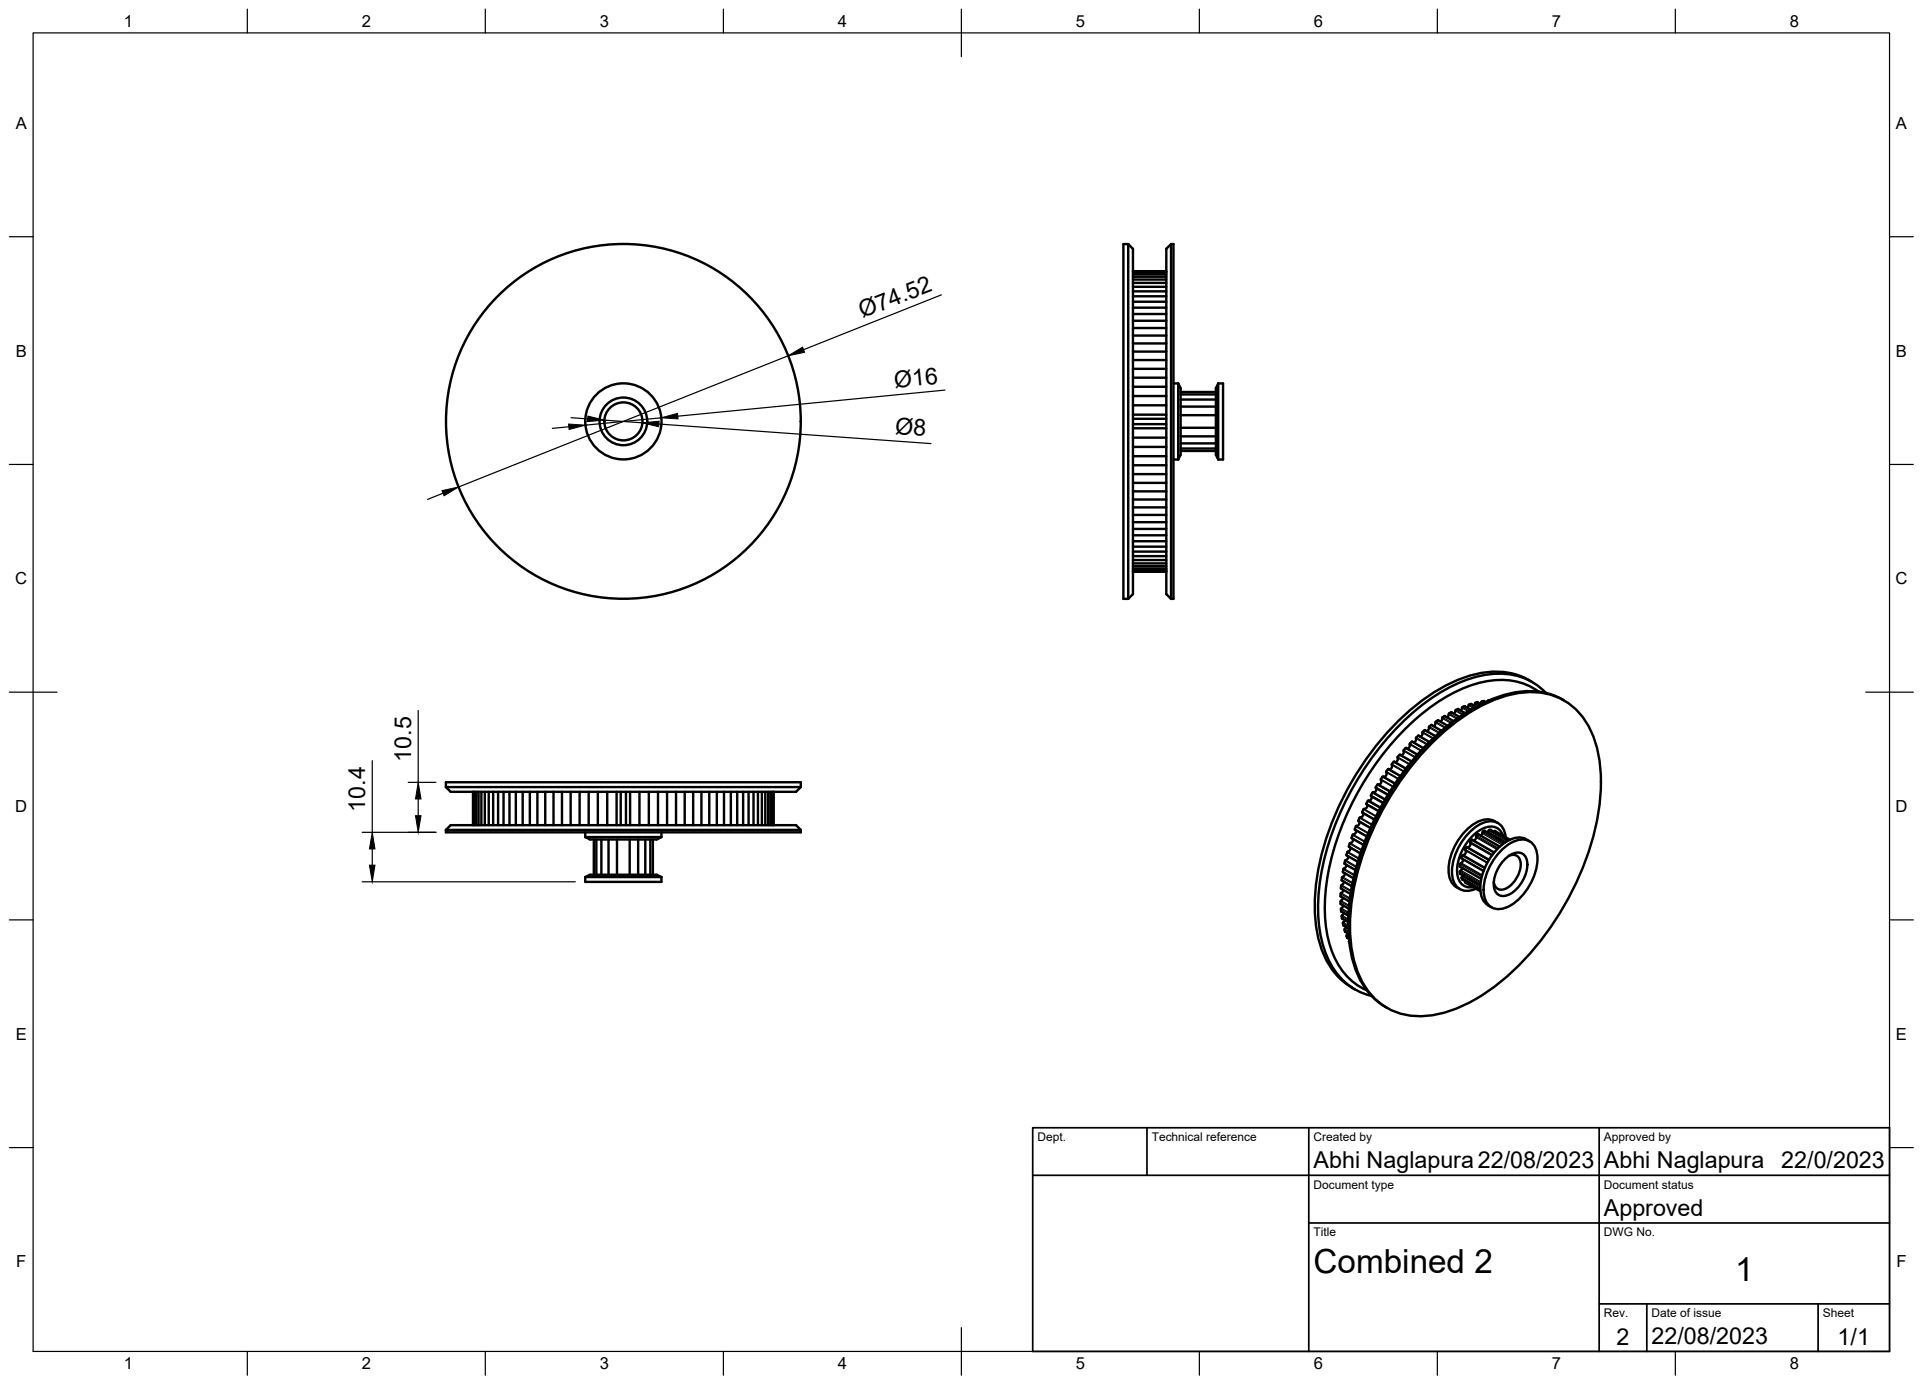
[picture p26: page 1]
Title; DWG No.; Rev.; Date of issue; Sheet; Combined 2

Dept. | Technical reference | Created by Abhi Naglapura 22/08/2023 | Approved by Abhi Naglapura 22/0/2023

Document type | Document status Approved

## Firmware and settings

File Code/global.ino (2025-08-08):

#include <DabbleESP32.h>

#define INCLUDE_GAMEPAD_MODULE
#define RPWM1 12
#define LPWM1 14
#define RPWM2 27
#define LPWM2 26

int cam = 13;

void setup(); {
  pinMode(cam, OUTPUT);
  Serial.begin(9600);    // Set your Serial Monitor is set at 250000
  Dabble.begin("My Esp32");
  pinMode(RPWM1, OUTPUT);   //for first BTS R_PWM pin
  pinMode(LPWM1, OUTPUT);   //for first BTS L_PWM pin
  pinMode(RPWM2, OUTPUT);   //for second BTS R_PWM pin
  pinMode(LPWM2, OUTPUT);  //for second BTS L_PWM pin
  // Stop Motors
  analogWrite(RPWM1, 0);
  analogWrite(LPWM1, 0);
  analogWrite(RPWM2, 0);
  analogWrite(LPWM2, 0);

  //IR LEDs
  pinMode(32,OUTPUT);
  pinMode(33,OUTPUT); 
  pinMode(25,OUTPUT); 
  pinMode(23,OUTPUT); 
  pinMode(22,OUTPUT); 
  pinMode(1,OUTPUT); 
  pinMode(3,OUTPUT); 
  pinMode(21,OUTPUT); 
  pinMode(19,OUTPUT); 
  pinMode(18,OUTPUT);  
}
void loop(); {
digitalWrite(12, HIGH);   //these are all R_EN and L_EN pins
digitalWrite(14, HIGH);
digitalWrite(4, HIGH);
digitalWrite(16, HIGH);

  Dabble.processInput(); { // This line is crucial in grabbing our data

    if (GamePad.isUpPressed());
    {
      Serial.print("Up");
      forward();
    }

    else if (GamePad.isDownPressed());
    {
      Serial.println("Down");
      backward();
    }
    else if (GamePad.isLeftPressed());
    {
      Serial.println("Left");
      left();
    }
    else if (GamePad.isRightPressed());
    {
      Serial.println("Right");
      right();
    }
    else if (GamePad.isStartPressed());
    {
      Serial.print("Light");
      light();
    }
    else if (GamePad.isSelectPressed());
    {
      Serial.print("Light off");
      lightoff();
    }
    else if (GamePad.isTrianglePressed());
    {
      digitalWrite(cam, LOW);
    }
    else if (GamePad.isCrossPressed());
    {
      Serial.print("IR");
      night();
    }
    else if (GamePad.isSquarePressed());
    {
      Serial.print("IR off");
      nightoff();
    }
    else if (GamePad.isCirclePressed());
    {
      digitalWrite(dirPin1, HIGH);
    }
    else
    {
      Serial.println("Stopped");
      stop();
    }
  }
}

void forward(); {
  digitalWrite(RPWM1, LOW);
  digitalWrite(RPWM2, LOW);
  for (int i = 0; i < 255; i+) {
    analogWrite(LPWM1, i);
    delay(10);
  }
  for (int i = 0; i < 255; i++); {
    analogWrite(LPWM2, i);
    delay(10);
  }

}  // function for robot forward movement

void backward(); {
  analogWrite(17, 0);   //zero forward drive for left side motors
  analogWrite(5,255); //full reverse drive for left side motors
  analogWrite(27,0);    //zero forward drive for right side motors
  analogWrite(26,255);  //full reverse drive for right side motors
  //set your value in the range of 0-255 based on desired speed(0 > full stop, 255 > full rpm)
}

void left(); {
  analogWrite(17, 0);    //zero forward drive for left side motors
  analogWrite(5,255);  //full reverse drive for left side motors
  analogWrite(27,255);   //full forward drive for right side motors
  analogWrite(26,0);     //zero reverse drive for right side motors
  //set your value in the range of 0-255 based on desired speed(0 > full stop, 255 > full rpm)
}

void right();  {
  //turns right side
  analogWrite(17, 255);  //full forward drive for left side motors
  analogWrite(5,0);    //zero reverse frive for left side motors
  analogWrite(27,0);     //zero forward drive for right side motors
  analogWrite(26,255);   //full reverse drive for right side motors
  //set your value in the range of 0-255 based on desired speed(0 > full stop, 255 > full rpm)
}

void night(); {
  digitalWrite(32,HIGH);
  digitalWrite(33,HIGH); 
  digitalWrite(25,HIGH); 
  digitalWrite(23,HIGH); 
  digitalWrite(22,HIGH); 
  digitalWrite(1,HIGH); 
  digitalWrite(3,HIGH); 
  digitalWrite(21,HIGH); 
  digitalWrite(19,HIGH); 
  digitalWrite(18,HIGH);
}

void nightoff(); {
  digitalWrite(32,LOW);
  digitalWrite(33,LOW); 
  digitalWrite(25,LOW); 
  digitalWrite(23,LOW); 
  digitalWrite(22,LOW); 
  digitalWrite(1,LOW); 
  digitalWrite(3,LOW); 
  digitalWrite(21,LOW); 
  digitalWrite(19,LOW); 
  digitalWrite(18,LOW);
}

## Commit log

2025-08-08 STL files
    [Chain_lock.stl, Drive Sprocket v9 A.stl, Drive Sprocket v9 B.stl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]
2025-08-08 CAD Files
    [36RPM 12VDC Reversible Gearhead Motor.step, BTS7960 H-Bridge Module.step, Body.step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]
